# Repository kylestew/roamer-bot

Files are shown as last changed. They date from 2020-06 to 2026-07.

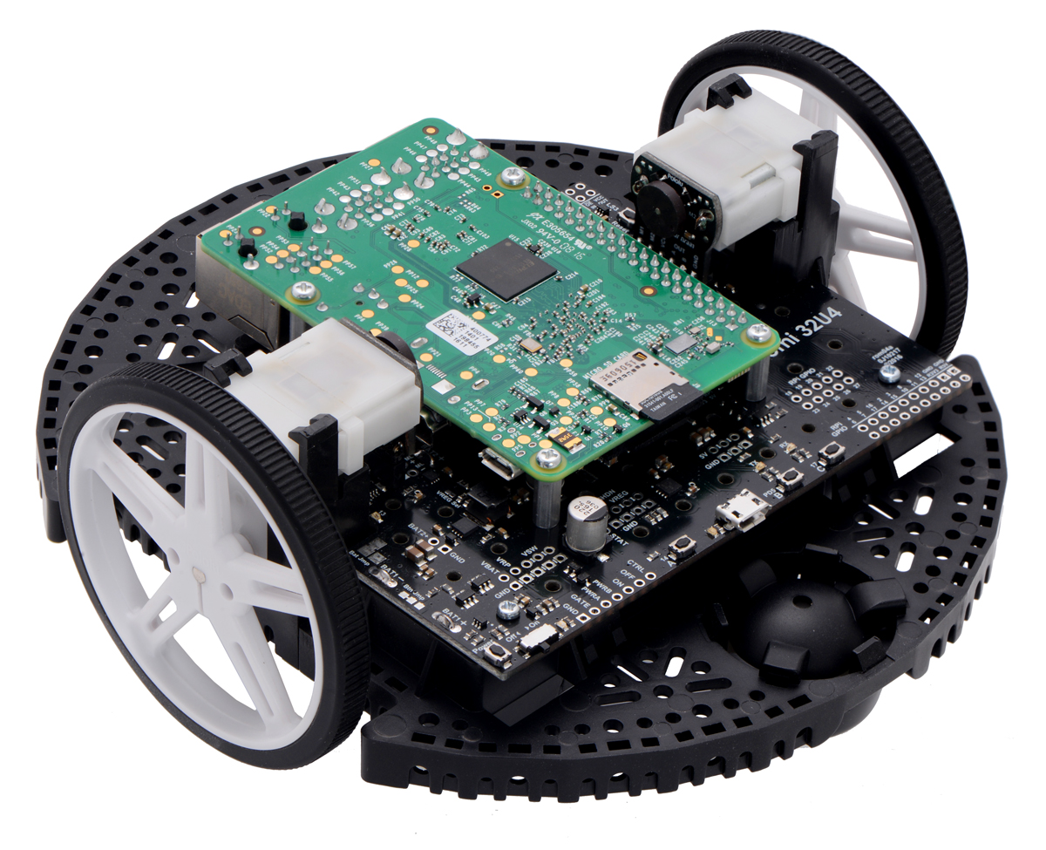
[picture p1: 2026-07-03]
docs/0J7520.1200.jpg

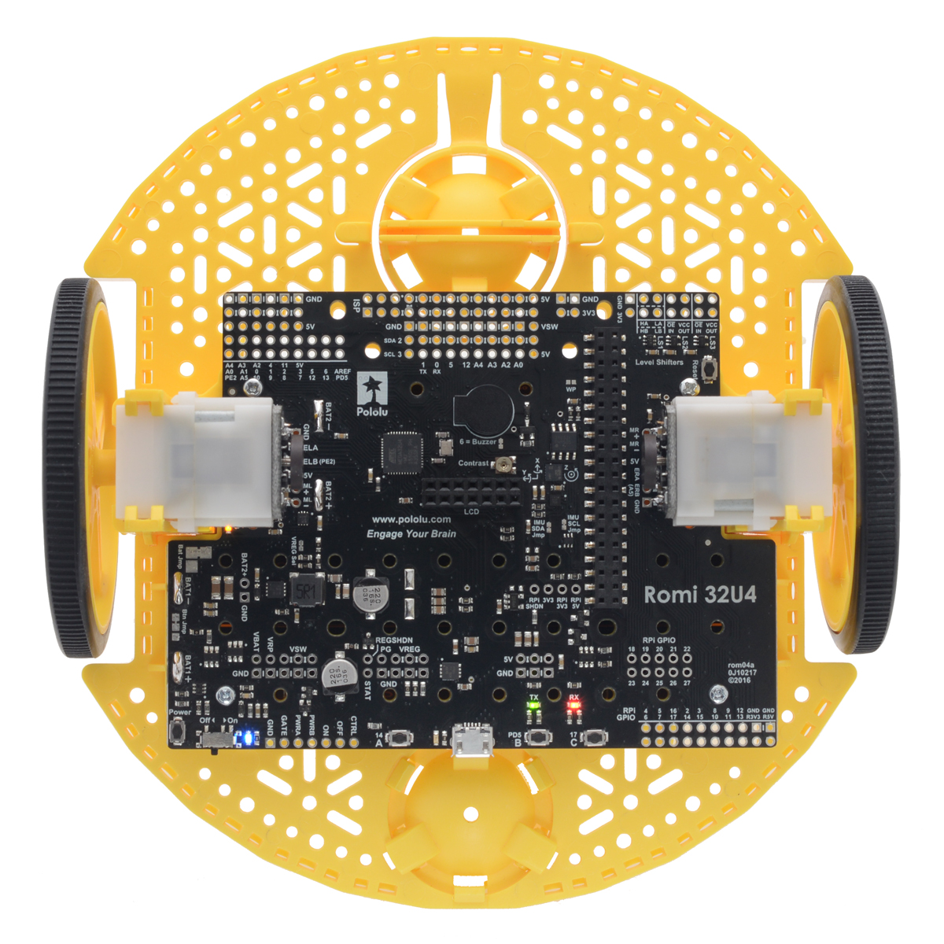
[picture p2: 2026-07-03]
docs/0J7519.1200.jpg

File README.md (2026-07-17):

# roamer-bot

A small robotics learning platform built on the Pololu Romi chassis.

The current direction is a custom-core Studio Mission Rover: Romi chassis, custom MCU + motor-control PCB, laptop tether first, telemetry from day one, and no ROS in the core system until the low-level robot is understood.

romi chassis

# Current Direction

The project is moving from the original Romi 32U4 + Raspberry Pi + ROS approach toward a custom-core learning build:

- Treat the old implementation as historical/reference material.
- Use the Romi chassis as the mechanical target.
- Build a custom MCU + motor-control PCB that replaces the purchasable Pololu Romi control board.
- Keep the first version tethered to a laptop.
- Capture telemetry from day one.
- Keep ROS out of the core system until the custom board, telemetry, and motor-control loop are understood.

# Current Structure

- `hardware/`: active Rev A PCB and mechanical-constraint work.
- `firmware/`: active custom MCU firmware work.
- `host/`: active laptop tether, telemetry capture, and test tooling work.
- `legacy/old-romi/`: previous Romi 32U4 + Raspberry Pi + ROS implementation, kept only as reference.
- `docs/`: datasheets, Romi reference assets, and legacy dependency references.

# Planning

- [Hardware design, release gate, and Rev B plan](hardware/README.md)
- [Studio Mission Rover roadmap](STUDIO_MISSION_ROVER_ROADMAP.md)
- [TO BUY list](TO_BUY.md)
- [Legacy Romi references](docs/legacy-romi-references.md)

# First Milestone

Teleop + encoder logging + safe stop:

- Command left and right motors from a laptop or simple host.
- Read left and right encoder counts.
- Stream basic telemetry.
- Stop motors on command timeout.
- Save a short bench or floor test log on the host.

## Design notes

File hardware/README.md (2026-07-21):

# Roamer Hardware

Status: **Rev A was ordered from JLCPCB on 2026-07-18 and is in production; fabrication and bring-up verification remain.**

This is the single source of truth for the custom Romi motor-controller hardware. If this document disagrees with the KiCad design, the schematic, PCB, and generated BOM are authoritative and this document must be corrected.

## Objective

Rev A replaces the Pololu Romi controller for the minimum useful rover loop:

- independently command two brushed DC motors;
- count both quadrature encoders in hardware;
- communicate with a laptop over native USB;
- report battery, motion, timeout, and reset state;
- stop both motors safely when commands cease; and
- mount directly to the Romi chassis and encoder boards.

Rev A is intentionally a focused learning board. It does not include an IMU, Raspberry Pi interface or power supply, wireless, charging, a 5 V accessory rail, or a polished multi-source power system.

Success means teleoperation, reliable encoder logging, useful telemetry, and an unconditional command-timeout stop during a short bench or floor run.

## Design Files

- [Top-level schematic](driver-board/driver-board.kicad_sch)
- [Power sheet](driver-board/power.kicad_sch)
- [Motor-control sheet](driver-board/motor_control.kicad_sch)
- [USB sheet](driver-board/usb.kicad_sch)
- [PCB](driver-board/driver-board.kicad_pcb)
- [KiCad project](driver-board/driver-board.kicad_pro)
- [Generated BOM snapshot](driver-board/driver-board.csv)
- [Rev A JLCPCB manufacturing release](releases/rev-a-jlcpcb-2026-07-18.md)
- [Custom footprints](driver-board/CustomParts.pretty/)

The checked-in CSV is a working snapshot, not purchase-ready assembly data. Regenerate and review the BOM and placement file from the final schematic and PCB immediately before ordering.

## Rev A Architecture

### Battery and power

Rev A is designed only for the Romi six-AA bay populated with rechargeable NiMH cells:

- nominal pack voltage: approximately 7.2 V;
- fresh-pack voltage: approximately 8.4 V;
- bench-supply ceiling: 8.5 V; and
- alkaline cells are prohibited because a fresh pack can approach 9.6 V, reducing DRV8838 transient margin and increasing motor stall current beyond the intended operating envelope.

The implemented load-current path is:

```text
BT1+ -> VBAT -> F1 -> Q1 -> VBAT_SAFE -> Q2 -> VBAT_SW
BT1- -> BT2+
BT2- -> GND
```

- F1 is a Littelfuse `MINISMDC260F/16-2` resettable PTC: 16 V, 2.6 A hold, 5 A trip.
- Q1 (`AO3401A`) provides reverse-battery protection.
- Q2 (`AO4407A`) is the high-side whole-board power MOSFET.
- SW2 (`SK-3296S-01-L2`) switches Q2's gate; it does not carry motor or regulator load current.
- `VBAT_SW` feeds both motor-driver VM inputs, both encoder boards, and the 3.3 V buck regulator.
- USB VBUS is used only around the USB interface. It does not power `+3V3`, the encoders, or the motors.

The LMR51430 buck, 5.6 uH L1, and output network generate approximately 3.3 V from `VBAT_SW`. There is no 5 V logic rail, separate `+3V3A` rail, or analog-rail inductor. VDDA is fed directly from `+3V3` with local 10 nF and 1 uF decoupling.

Battery telemetry uses a 100 kOhm / 33 kOhm divider into PB0/ADC1_IN8. Rev A deliberately omits a filter capacitor; firmware must use a long ADC sample time and modest averaging. This is approximate state telemetry, not precision fuel gauging.

### Motor power and protection

Rev A uses one TI DRV8838 per motor. The target motor is the Pololu #1520 120:1 high-power mini plastic gearmotor, specified around 3-6 V with approximately 1.25 A stall current at 4.5 V.

Normal firmware output is capped at 75% absolute PWM duty, following the Pololu Romi operating policy. Full-duty operation is diagnostic-only, with a current-limited supply and explicit test firmware.

Motor-rail capacitance is:

| Driver | VM high-frequency bypass | VM local storage | VCC bypass |
| --- | --- | --- | --- |
| U3, left | C11, 100 nF | C10, 10 uF | C12, 100 nF |
| U4, right | C14, 100 nF | C13, 10 uF | C15, 100 nF |

C16 is a shared 220 uF, 25 V bulk capacitor across `VBAT_SW` and GND. It buffers short current steps and returned energy but does not replace the battery as the sustained current source. Rev A has no TVS or characterized regenerative clamp; startup, stop, reversal, stall-release, and power-off peaks must be measured during bring-up.

Each DRV8838 `nSLEEP` input has a hardware pulldown. Firmware must also initialize `nSLEEP`, PWM/EN, and PH to disabled states before accepting commands. A host timeout, watchdog event, low-battery condition, or unsafe state commands PWM to zero and puts the drivers to sleep while the MCU remains powered.

DRV8838 provides no fault or current-sense output. Diagnose problems through commanded state, encoder response, battery voltage, reset cause, temperature, and measured supply waveforms.

### Motor and encoder connectors

The encoder boards are powered from `VBAT_SW` because their specified VCC range begins above 3.3 V. Their A/B outputs are open-drain and pulled up to `+3V3`, so the STM32 receives safe 3.3 V logic. Firmware must treat encoder counts as unreliable when the battery approaches the encoder's 3.5 V minimum plus margin.

Viewed from the top of the PCB:

| Connector | Top-to-bottom pin order |
| --- | --- |
| J4, left | `GND`, `ENC_L_A`, `ENC_L_B`, `VBAT_SW`, `ML+`, `ML-` |
| J3, right | `MR-`, `MR+`, `VBAT_SW`, `ENC_R_A`, `ENC_R_B`, `GND` |

The right connector is intentionally mirrored for cleaner symmetric routing and does not reproduce the Pololu silkscreen order. Confirm actual wheel-forward polarity and encoder count sign during bring-up; correct direction convention in firmware rather than casually changing the verified connector layout.

### MCU and firmware-facing pin contract

U1 is an `STM32F103CBT6` in LQFP-48 with a 16 MHz HSE crystal, native USB FS, SWD, two hardware encoder timers, two PWM channels, and battery ADC input.

| Function | MCU pin | Peripheral or mode |
| --- | --- | --- |
| Heartbeat LED | PC13 | GPIO, active-low |
| Left sleep | PB12 | GPIO, active-low |
| Left direction | PB13 | GPIO |
| Left PWM | PB14 | TIM1 CH2N |
| Right sleep | PB5 | GPIO, active-low |
| Right direction | PB6 | GPIO |
| Right PWM | PB7 | TIM4 CH2 |
| Left encoder A/B | PA6 / PA7 | TIM3 CH1 / CH2 |
| Right encoder A/B | PB3 / PA15 | TIM2 CH2 / CH1, partial remap 1 |
| Battery level | PB0 | ADC1 IN8 |
| USB D-/D+ | PA11 / PA12 | USB FS |
| SWDIO/SWCLK | PA13 / PA14 | SWD; SWO is not connected |

The MCU contains I2C2 on PB10/PB11, but those package pins are explicit no-connects on Rev A. There are no pullups, connector, or sensor footprint, so Rev A has no usable I2C bus. Remove the stale I2C2 assignment from the CubeMX design artifact before release. User buttons and additional controlled status LEDs are also deferred; Rev A has reset, a power LED, and one MCU heartbeat/status LED.

SWD is the primary programming and recovery path. The 1.27 mm 2x5 header exposes target power, GND, SWDIO, SWCLK, and NRST; the target supplies its own 3.3 V.

### USB policy

J2 is a USB-C USB 2.0 receptacle with 5.1 kOhm CC resistors and USBLC6-2 ESD protection. D+/D- run directly to the STM32 without external series resistors and are routed via-free on `F.Cu` over the solid ground plane.

Rev A is battery-powered and USB-data-only:

- USB alone leaves the board off.
- Battery/bench power with USB disconnected supports standalone operation.
- Battery/bench power plus USB supports programming, commands, and telemetry without backfeeding the board from VBUS.

R5 permanently enables the external D+ pullup whenever board 3.3 V is present; attachment is not gated by VBUS. Rev A therefore assumes connection to an already-powered host. If enumeration fails after connection to an unpowered or booting host, unplugging and reconnecting USB is the accepted recovery. Add VBUS sensing and pullup gating in Rev B if reliable or standards-compliant self-powered attachment is required.

## PCB and Manufacturing Policy

Rev A is a four-layer, approximately 1.6 mm FR-4 board:

| Layer | Primary use |
| --- | --- |
| `F.Cu` | Components, signals, short local power pours, and regulator switching loops |
| `In1.Cu` | Continuous GND plane; never split into motor and logic grounds |
| `In2.Cu` | `VBAT_SW` and `+3V3` power distribution |
| `B.Cu` | Lower-speed signals plus a stitched GND fill |

Rules to preserve:

- Keep USB, clocks, feedback, ADC, reset, and other sensitive signals over continuous ground.
- Do not route a bottom-layer signal across an `In2.Cu` power split without a same-layer or otherwise continuous return reference.
- Keep the U5 VIN, bootstrap, switch-node, inductor, output-capacitor, and feedback loops compact.
- Keep motor-current paths and returns short and broad, with multiple vias where current changes layers.
- Keep the DRV8838 exposed-pad solder areas free of drilled holes. The implemented nearby ordinary GND vias require no via-in-pad fill or cap process.
- Keep motor current away from encoder, USB, crystal, reset, SWD, and BATLEV routing.

The smallest intentional signal vias are 0.55 mm diameter with a 0.25 mm drill. These are within JLCPCB rigid-board capability and have a 0.15 mm radial annular ring. Continue to use 0.70/0.30 mm or larger vias for high-current, thermal, and principal ground paths when space permits.

Silkscreen is front-side only. The board includes assembly and connector labels, polarity and pin-1 marks, test-point labels, board/battery identification, and the capybara artwork. There is no back silkscreen.

Mechanical fit has been checked repeatedly against the Romi chassis, encoder boards, battery contacts, wheels, clips, ribs, caster area, mounting holes, switch access, and USB cable access. Preserve the verified board outline and chassis-critical footprints.

## Current Verification State

As of 2026-07-21:

- JLCPCB order `W2026071807372374` is in production and its PCB production file is confirmed;
- the order contains five PCBs, including two economically assembled PCBAs;
- fabrication completion and physical bring-up remain;
- schematic ERC: **0 violations**;
- PCB DRC: **0 violations**;
- PCB connectivity: **0 unconnected items**;
- SW2 SMD-anchor pad semantics and silkscreen clearances are fixed in both the library footprint and board instance; and
- top, bottom, and isometric views plus a 1:1 chassis comparison have been reviewed.

The KiCad project intentionally excludes several generic checks, including missing courtyards, track endpoints not centered on vias, tuning-profile geometry, footprint filters, and footprint type. A clean report means the active Rev A rule set passes; it does not replace the fabrication preview and manual checks below.

## Fabrication Release Gate

Complete every item before ordering:

- [ ] Remove the unusable I2C2 PB10/PB11 assignment from the CubeMX artifact and keep I2C, user buttons, and extra LEDs explicitly deferred to Rev B.
- [ ] Refill all zones, complete the final GND-stitching pass, and confirm no isolated copper islands.
- [ ] Rerun ERC and PCB DRC with schematic parity, warnings, exclusions, and zero unconnected items reviewed.
- [ ] Reinspect the complete power path, battery series link, Q1/Q2 orientation, both driver VM/output/ground loops, U5 layout, USB routing, NRST, BOOT0, oscillator, and MCU decoupling.
- [ ] Verify both `nSLEEP` pulldowns hold the drivers off during reset, boot, SWD attach, unpowered-MCU states, and firmware initialization.
- [ ] Verify BATLEV stability with motors and the buck switching; accept the unfiltered divider only if firmware sampling is adequate.
- [ ] Confirm the actual JLCPCB stackup and USB geometry, drill and slot sizes, annular rings, mask dams, copper-edge clearance, and silkscreen capability.
- [ ] Regenerate the BOM and CPL/position data from the final design.
- [ ] Fill or explicitly waive every missing JLCPCB field, especially C22, C23, R5, R12, R13, and R16-R19.
- [ ] Manually verify U1, U3/U4, U5, F1, Q1, Q2, SW2, J2, J3/J4, L1, C16, and C17-C21 against current value, package, polarity, voltage/current rating, lifecycle, and stock.
- [ ] Review Gerbers, drills, IPC netlist, BOM, and CPL independently, then inspect the JLCPCB fabrication and assembly previews for side, rotation, pin 1, polarity, DNP state, and footprint alignment.
- [ ] Archive the exact schematic, PCB, fabrication outputs, BOM, CPL, and firmware revision used for the build.

Useful release commands:

```sh
/Applications/KiCad/KiCad.app/Contents/MacOS/kicad-cli sch erc \
  --severity-all hardware/driver-board/driver-board.kicad_sch

/Applications/KiCad/KiCad.app/Contents/MacOS/kicad-cli pcb drc \
  --schematic-parity --severity-all \
  hardware/driver-board/driver-board.kicad_pcb
```

## Bring-Up Plan

1. Inspect polarity, orientation, shorts, solder joints, and the unpowered resistance of each rail.
2. Use a current-limited bench supply at a low voltage with motors disconnected; verify `VBAT`, `VBAT_SAFE`, `VBAT_SW`, and `+3V3` in order.
3. Verify SW2/Q2 behavior, Q1 reverse protection, no USB backfeed, and USB-only board-off behavior.
4. Attach SWD, confirm NRST/BOOT behavior, program the safe image, and prove both `nSLEEP` inputs and PWM outputs remain inactive through reset and debugger attach.
5. Confirm the 16 MHz HSE/48 MHz system clock, heartbeat LED, USB enumeration, battery ADC reading, and reset-cause telemetry.
6. Connect one motor and its encoder. Start at low duty, verify direction/count sign, sweep duty conservatively, and test timeout stop.
7. Repeat for the other motor, then operate both together while checking encoder integrity and the 3.3 V rail.
8. With a short oscilloscope ground spring, capture `VBAT_SW` at C16 and each driver during start, stop, reversal, simultaneous start, stall release, and power-off at nominal and fresh-pack voltage.
9. Check the PTC, MOSFETs, regulator, inductor, motor drivers, connectors, and C16 temperature during an extended test.
10. Run low-speed straight, turn, stop, and host-disconnect floor tests while saving telemetry.

Bring-up passes when both motors operate independently in both directions, encoder counts remain clean, PWM response is monotonic, command timeout and watchdog stop the motors, USB remains stable, and motor events do not reset the MCU or violate measured rail margins.

Record Rev A current, voltage transients, temperatures, resets, encoder errors, mechanical fit, and USB behavior. Those measurements—not guesses—select Rev B protection and power changes.

## Critical Parts

| Function | Part | Current JLCPCB/LCSC ID |
| --- | --- | --- |
| MCU | STM32F103CBT6 | C8304 |
| Motor drivers | DRV8838, U3/U4 | C86667 |
| Buck regulator | LMR51430XDDCR | C5185863 |
| Buck inductor | SWPA8065S5R6MT, 5.6 uH | C96977 |
| USB ESD | USBLC6-2SC6 | C7519 |
| USB-C connector | GT-USB-7010ASV | C2988369 |
| Input PTC | MINISMDC260F/16-2 | C16490 |
| Reverse-protection MOSFET | AO3401A | C15127 |
| Power MOSFET | AO4407A | C16072 |
| Power switch | SK-3296S-01-L2 | C500051 |
| Bulk capacitor | 220 uF, 25 V | C190724 |
| HSE crystal | 16 MHz, 3225 | C13738 |

Recheck every ID and stock state at order time; this table records the design, not a sourcing guarantee.

## Rev B Backlog

Rev B begins only after Rev A assembly and measured testing. Priorities are:

1. Correct every demonstrated Rev A electrical, mechanical, sourcing, or firmware-contract defect.
2. Retain USB and add a 3.3 V UART host interface; keep motor safety, encoder counting, timeout, and low-level control on the STM32.
3. Add a 6-axis IMU and an isolatable 3.3 V I2C/Qwiic-style sensor connector.
4. Consider an unpopulated Pi-compatible header, but default to a separately powered host sharing only communications and GND. Do not advertise HAT compatibility without meeting the complete specification.
5. Add VBUS sensing and gated USB attachment; optionally support USB/host-powered logic while guaranteeing the motor rail remains off and no source can backfeed another.
6. Add snubber, clamp/TVS, distributed bulk-capacitance, current-sense, or fault-reporting provisions only where Rev A measurements justify them.
7. Consider a diagnostic motor driver such as DRV8213 and a newer MCU such as STM32G0B1 only if Rev A exposes a concrete limitation.
8. Do not add a magnetometer beside motors or an unrestricted multi-amp Pi supply by default. Remote magnetic sensing and host power require explicit mechanical and power requirements.

Any host reset, disconnect, or brownout must still cause the STM32 watchdog to stop the motors safely.

## References and Asset Provenance

Local vendor references retained as primary sources:

- [STM32F103 datasheet](docs/stm32f103c8.pdf)
- [DRV8838 datasheet](docs/drv8838.pdf)
- [LMR51430 datasheet](docs/lmr51430.pdf)
- [AO4407A / C16072 reference](docs/C16072.pdf)
- [SK-3296S-01-L2 / C500051 reference](docs/C500051.pdf)
- [Reset switch / C720477 reference](docs/C720477.pdf)
- [Alternate switch / C1788495 reference](driver-board/datasheets/C1788495.pdf), not fitted on current Rev A

External design references:

- [Pololu Romi 32U4 control-board guide](https://www.pololu.com/docs/0J69/all)
- [Pololu Romi 32U4 resources](https://www.pololu.com/product/3544/resources)
- [Pololu #1520 motor](https://www.pololu.com/product/1520)
- [Pololu Romi encoder pair](https://www.pololu.com/product/3542)
- [ST USB hardware and PCB guidelines, AN4879](https://www.st.com/resource/en/application_note/an4879-introduction-to-usb-hardware-and-pcb-guidelines-using-stm32-mcus-stmicroelectronics.pdf)
- [Samsung CL21A106KAYNNNE data](https://product.samsungsem.com/mlcc/CL21A106KAYNNN.do)
- [Raspberry Pi hardware documentation](https://www.raspberrypi.com/documentation/computers/raspberry-pi.html)

3D-model provenance:

- `driver-board/3dmodels/GT-USB-7010ASV.step` comes from the GPL-2.0-licensed [MiSTerLaggy_MiSTer hardware repository](https://github.com/MiSTer-devel/MiSTerLaggy_MiSTer/blob/main/hardware/GT-USB-7010ASV.step).
- `driver-board/3dmodels/SK-3296S-01-L2.wrl` was converted without changing millimetre-scale alignment from the [EasyEDA model](https://modules.easyeda.com/3dmodel/a3deeb560a8c4467ab29e6daf75b62b9) for [LCSC C500051](https://www.lcsc.com/product-detail/Electrical-Switches_XKB-Connectivity-SK-3296S-01-L2_C500051.html).

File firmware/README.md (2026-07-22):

# Firmware

Active firmware work for the STM32 MCU on the Rev A motor-control board.

The firmware is bare-metal C11 for the `STM32F103CBT6`. It uses CMSIS register
definitions but no STM32 HAL, LL framework, RTOS, heap, or generated runtime
code. [`roamer_rev_a.ioc`](roamer_rev_a.ioc) records the planned pin and clock
assignment; it is a design artifact rather than the firmware generator.

## Build

Requirements:

- Arm GNU Toolchain (`arm-none-eabi-gcc`, `objcopy`, and `size`)
- CMake 3.22 or newer
- Ninja

From the repository root:

```sh
cmake -S firmware -B firmware/build-debug -G Ninja -DCMAKE_BUILD_TYPE=Debug
cmake --build firmware/build-debug

cmake -S firmware -B firmware/build-release -G Ninja -DCMAKE_BUILD_TYPE=Release
cmake --build firmware/build-release
```

Each build produces `roamer_rev_a.elf`, `.hex`, `.bin`, and `.map` files and
prints Flash/RAM use.

## Program and debug

SWD is the primary programming and recovery interface. The board has a
1.27 mm MIPI10/Arm Cortex debug header; an STLINK-V3SET includes the matching
cable. The target must supply its own 3.3 V power. Keep the motors disconnected
during initial bring-up.

With `STM32_Programmer_CLI` on `PATH` and an ST-LINK attached:

```sh
STM32_Programmer_CLI -c port=SWD -w firmware/build-release/roamer_rev_a.hex -v -rst
```

The initial image keeps both DRV8838 drivers asleep and both PWM inputs low.
PC13 blinks with a one-second cycle after the 16 MHz HSE starts and the system
switches to 48 MHz. A rapid blink indicates that firmware remained on the
8 MHz internal oscillator because HSE startup failed. USB is enabled only when
the 48 MHz clock is available.

## USB heartbeat bring-up

Rev A is self-powered and uses USB only for data. Power the board from its
battery or a current-limited bench supply, connect it to an already-powered
host, and then look for the CDC ACM serial device. USB alone does not power the
board.

On macOS, find and open the device with:

```sh
ls /dev/cu.usbmodem*
screen /dev/cu.usbmodem* 115200
```

The baud-rate setting is accepted for CDC compatibility but does not control a
physical UART. While the serial port is open, the firmware sends one line per
second:

```text
roamer heartbeat
```

Close `screen` with `Ctrl-A`, then `\`. The PC13 LED continues blinking while
USB is connected. Motor commands and received serial data are not supported by
this bring-up image; received bytes are discarded and both drivers remain
asleep.

The USB identity is development-only: VID `0xCAFE`, PID `0x4001`, manufacturer
`Roamer`, and product `Roamer Rev A`. The serial string comes from the MCU's
96-bit unique ID. Replace the prototype VID/PID with assigned values before any
product distribution.

Rev A has a permanently enabled D+ pullup and no VBUS sensing. Firmware pulses
D+ low during startup to encourage clean re-enumeration after reset, but if the
host does not rediscover the device, unplug and reconnect the USB cable as
documented in the hardware policy.

## Verified Rev A pin contract

| Function | MCU pin | Peripheral/mode |
| --- | --- | --- |
| Heartbeat LED | PC13 | GPIO, active-low |
| Left sleep | PB12 | GPIO, active-low |
| Left direction | PB13 | GPIO |
| Left PWM | PB14 | TIM1 CH2N |
| Right sleep | PB5 | GPIO, active-low |
| Right direction | PB6 | GPIO |
| Right PWM | PB7 | TIM4 CH2 |
| Left encoder A/B | PA6 / PA7 | TIM3 CH1 / CH2 |
| Right encoder A/B | PB3 / PA15 | TIM2 CH2 / CH1, partial remap 1 |
| Battery level | PB0 | ADC1 IN8 |
| USB D-/D+ | PA11 / PA12 | USB FS |
| SWDIO/SWCLK | PA13 / PA14 | Debug; SWO is not connected |

The CubeMX design artifact also assigns I2C2 SCL/SDA to PB10/PB11, but those two MCU pads are explicit no-connects in the Rev A schematic and PCB. There are no I2C pullups or external connection, so I2C2 is not physically usable on the current board. Route it before fabrication or remove the assignment and explicitly descope the Rev A expansion bus.

Initial firmware should support independent left/right motor commands, encoder counting, basic telemetry, battery reporting, and command-timeout safe stop.

Hardware-facing firmware requirements are tracked in the [Rev A hardware specification](../hardware/README.md#mcu-and-firmware-facing-pin-contract).

Accepted behavior and safety policies are tracked in [Rev A firmware design](DESIGN.md), including the six-cell NiMH motor-power baseline and 75% normal-duty ceiling.

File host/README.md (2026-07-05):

# Host

Active laptop-side tooling for Rev A bring-up.

Initial host tools should send motor commands over USB or serial, capture telemetry, save short run logs, and make bench/floor tests repeatable.

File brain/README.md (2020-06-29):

# Brain - ROS workspace for Roamer Bot

### Notes:

brainstem package requires sudo-less i2c permissions 
https://lexruee.ch/setting-i2c-permissions-for-non-root-users.html

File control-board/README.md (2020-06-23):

# 32U4 Control Board

Provides the low-level operations for the Roamer Robot:

+ Motor control (w/PID) takes ROS Twist command data
+ Encoders publish robot ODOM
+ IMU publishes robot POSE
+ Auto shutdown if new Twist command not received in a defined period
+ Buttons
+ LEDs
+ Battery voltage

### I2C Interface

Bi-directional via a struct
???

## CLI Commands

Build firmware

    $ pio run -e robot

Upload firmware via bootloader

    $ pio run -e robot -t upload

Run native desktop test

    $ pio test -e native 

Run embedded test

    $ pio test -e robot

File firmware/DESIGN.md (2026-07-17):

# Rev A Firmware Design

Status: active decisions

This document records firmware behavior that is required by the Rev A hardware. Hardware-level requirements remain in the [Rev A hardware specification](../hardware/README.md).

## Motor and battery baseline

Rev A intentionally follows the proven Pololu Romi motor-power approach:

| Item | Rev A decision |
|---|---|
| Motor | [Pololu #1520](https://www.pololu.com/product/1520), 120:1 mini plastic gearmotor HP |
| Motor specification | 4.5 V intended, 3–6 V comfortable range, 1.25 A stall at 4.5 V |
| Battery | Six rechargeable AA NiMH cells only |
| Pack voltage | About 7.2 V nominal and approximately 8.4 V when freshly charged |
| Motor driver | One DRV8838 per motor |
| Driver supply | Raw reverse-protected and switched battery rail, `VBAT_SW` |
| Normal PWM ceiling | 75% absolute duty cycle |

Alkaline cells are outside the Rev A operating specification. Six alkaline cells have a substantially higher pack voltage than six NiMH cells and must not be treated as an interchangeable option.

Pololu's Romi 32U4 board uses the same motors, six-cell battery arrangement, raw switched battery motor supply, and DRV8838 drivers. Its normal motor API limits output to 300 of 400 PWM counts, or 75% duty. Pololu describes the full 400-count range as turbo mode and warns that it can reduce motor lifetime.

## Motor output policy

- Clamp every open-loop, closed-loop, and host-requested motor command to an absolute duty cycle of `0.75` in normal operation.
- Apply the clamp at the final driver-output boundary as well as at command parsing. A malformed host command or controller wind-up must not bypass it.
- Do not expose turbo/full-duty operation in the normal Rev A host protocol.
- Full-duty testing, if ever needed, is a deliberate diagnostic operation performed locally with a current-limited bench supply and explicit test firmware.
- Battery-voltage feed-forward may reduce duty or improve repeatability below the ceiling. It must not silently raise the 75% ceiling.
- Record both requested and applied duty in telemetry so saturation is visible.

The 75% limit gives a rough effective motor voltage of 5.4 V from a 7.2 V pack and 6.3 V from an 8.4 V fresh pack. PWM is not identical to powering a motor from a lower DC voltage, so the limit does not guarantee current, thermal, or transient margin. Rev A accepts motor-rail transient characterization as deferred Rev B work.

## Driver state and safe stop

The DRV8838 PH/EN interface has an important semantic detail: `EN/PWM = 0` while awake commands brake, not coast. Pulling `nSLEEP` low disables the bridge and allows the motor to coast.

Required behavior:

1. Keep both drivers asleep during reset and early boot.
2. Initialize PWM to zero and direction to a known value before raising either `nSLEEP` signal.
3. Accept motor commands only after initialization and command-channel readiness.
4. On command timeout, malformed command, firmware fault, or explicit disable: set PWM to zero, then pull both `nSLEEP` signals low.
5. Use 1000 ms as the initial command-timeout value; tune it later from command rate and measured stopping distance.
6. Require a new valid command sequence before re-enabling after a timeout or fault.
7. Never create torque during reset, boot, USB enumeration, host disconnect, or brownout recovery.

## Battery and drivetrain telemetry

`BATLEV` is intentionally a coarse battery estimate, not a precision measurement. Use an ADC sample time of at least 41.5 cycles, preferably 55.5 cycles, to accommodate the 100 kΩ/33 kΩ divider's source impedance. Apply modest averaging and the nominal divider ratio. No dedicated filter capacitor or production calibration is required, and firmware must not depend on a narrow BATLEV threshold for safety-critical behavior.

Minimum telemetry:

- measured battery voltage;
- requested and applied duty for each motor;
- active 75% duty ceiling and whether either command is saturated;
- direction and sleep state for each motor;
- encoder count and estimated wheel speed for each side;
- command age and timeout state;
- reset and brownout cause when available; and
- an inferred stall warning when substantial applied duty produces no encoder motion.

The DRV8838 provides neither a fault output nor current sensing, so firmware cannot directly identify over-current or thermal shutdown. Telemetry must not claim that an inferred stall is a measured driver fault.

## Encoder handling

- Verify the physical left/right direction convention during bring-up.
- Positive commands should produce forward wheel motion and positive encoder accumulation on both sides after the documented sign corrections.
- Handle hardware counter wrap with modular deltas and accumulate position in a wider software integer.
- Treat encoder data as unreliable if the switched battery rail falls close to the encoder board's minimum supply voltage.

## Board indicators

- D2, the PC13 status LED, is active-low.
- Drive PC13 low to turn D2 on and high to turn it off.
- Keep PC13 configured so it sinks LED current; do not reconfigure the circuit or firmware around sourcing current from PC13.

## Required validation

Before normal unrestricted use:

1. Bring up each motor independently from a current-limited bench supply at low duty.
2. Verify forward/reverse direction and encoder sign for both sides.
3. Sweep duty through the permitted range and confirm monotonic unloaded speed.
4. Repeat with fresh and depleted six-cell NiMH packs.
5. Run both motors together and confirm clean encoder readings and stable logic power.
6. Briefly test single- and dual-motor stalls within controlled limits while observing supply current and driver temperature.
7. Measure driver and motor temperature during representative driving.
8. Confirm the timeout and every reset/disconnect path puts both drivers to sleep.

Motor-rail transient characterization during braking, reversal, stall release, and power switch-off is planned for Rev B rather than being a Rev A acceptance criterion.

## References

- [Pololu #1520 motor](https://www.pololu.com/product/1520)
- [Pololu Romi motor drivers and encoders](https://www.pololu.com/docs/0J69/3.3)
- [Pololu Romi power architecture](https://www.pololu.com/docs/0J69/3.5)
- [Pololu Romi motor library](https://pololu.github.io/romi-32u4-arduino-library/class_romi32_u4_motors.html)
- [Pololu support explanation of the 75% limit](https://forum.pololu.com/t/isnt-the-9v-of-the-romi-batteries-too-high-for-the-4-5v-gearmotors/17486)
- [TI DRV8838 datasheet](https://www.ti.com/lit/ds/symlink/drv8838.pdf)

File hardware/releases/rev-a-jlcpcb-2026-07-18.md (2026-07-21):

# Rev A JLCPCB Manufacturing Release

Status: **In production as of 2026-07-21.**

This record identifies the first Rev A fabrication and assembly run and the exact local upload artifacts retained with the project.

## Order Record

The JLCPCB order page displayed the following information:

| Item | Recorded value |
| --- | --- |
| Order time | 2026-07-18 00:37:30, as displayed by JLCPCB |
| JLCPCB order | `W2026071807372374` |
| Overall status | In Production |
| PCB product | PCB Prototype |
| PCB order | `Y15-03620135F` |
| PCB quantity | 5 pieces |
| PCB build estimate | 3 days |
| PCB price | $30.98 |
| PCB production file | `Archive_Y15`; confirmed |
| Assembly product | Economic PCBA |
| PCBA order | Displayed beginning `SMT026071763327-362`; suffix not visible in the retained screenshot |
| PCBA quantity | 2 pieces |
| PCBA build estimate | 4 days |
| PCBA price | $84.98 |
| Assembly BOM | `driver-board-jlc-bom.csv` |
| Assembly CPL | `driver-board-jlc-cpl.csv` |
| Merchandise total | $115.96 |
| Shipping | $24.55 |
| Customs duties and taxes | $28.09 |
| Order total | $168.60 |

The order page does not show stackup, copper weight, surface finish, colour, or the other detailed fabrication selections. If those settings are later exported from JLCPCB, add them here without changing the archived upload artifacts.

## Archived Upload Artifacts

| File | SHA-256 |
| --- | --- |
| `driver-board/mfr/Archive.zip` | `2fa4bc9299dedf3daeadd7bcf76799896939166ab728aa14c1a1434a415308a5` |
| `driver-board/mfr/driver-board-jlc-bom.csv` | `09befc26d306caf2595d57af9a16463424a30b2fd342b907b6d6cff0e5063712` |
| `driver-board/mfr/driver-board-jlc-cpl.csv` | `672cb036feffceff9ac96b1f98a63404802aedea3e041ae011d15d0772670f0f` |

`Archive.zip` contains the submitted four-layer Gerbers and plated/non-plated drill files. The BOM and CPL are retained separately because JLCPCB accepts them as separate assembly uploads.

The Git tag `rev-a-jlcpcb-2026-07-18` identifies the repository checkpoint for this manufacturing run.

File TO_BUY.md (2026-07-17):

# TO BUY

Last reviewed: 2026-07-17

This is the purchasing list for the Rev A milestone: tethered teleoperation, encoder logging, and safe stop. Existing workshop and legacy-Romi inventory has not yet been checked, so items marked "if not already owned" should be verified before ordering.

## Buy Now

- [ ] **8 x AA NiMH cells from one matching batch.** Recommended: standard white Panasonic eneloop, 1.2 V, 1900 mAh minimum. The rover uses six cells; label and keep six as one set and retain two as spares. Buy twelve instead if a complete second six-cell set is useful.
  - Rev A is NiMH-only: about 7.2 V nominal and up to about 8.4 V just charged.
  - Do not use alkaline, 1.5 V lithium, or regulated/rechargeable 1.5 V AA cells.
  - Product reference: <https://www.panasonic.com/global/energy/products/eneloop/en/lineup/eneloop.html>
- [ ] **One individual-channel AA NiMH charger.** Recommended: Panasonic eneloop `BQ-CC63` eight-slot charger, in the UK-plug version. It charges and terminates each of 1-8 cells independently, so all six rover cells can be charged in one pass.
  - Charge the loose cells in the charger, not in the rover.
  - Product reference: <https://www.panasonic.com/global/energy/products/eneloop/en/lineup/charger-bq-cc63.html>
- [x] **One Pololu Romi Chassis Kit — purchased.** Any colour is electrically equivalent; the current project reference is white, Pololu `#3509`.
  - Includes chassis, two 120:1 HP motors, motor clips, two wheels, one ball caster, and the complete battery-contact set.
  - Product reference: <https://www.pololu.com/product/3509>
- [x] **One Pololu Romi Encoder Pair Kit — purchased.** Pololu `#3542`.
  - Includes two encoder boards, two magnetic discs, and the low-profile male/female headers needed by the custom PCB.
  - Product reference: <https://www.pololu.com/product/3542>
- [ ] **#2-56 mounting hardware:** at least four 3/16-inch screws and four nuts; buying a packet of ten gives useful spares. The chassis kit does not include this hardware.

The chassis and encoder kit should be in hand before PCB release so battery-tab polarity, connector fit, header height, and board clearance can be checked physically.

## Needed Before First Power-On

- [ ] **One SWD programmer/debugger with a Cortex-M MIPI-10 cable**, if not already owned. The PCB uses a keyed 10-pin, 1.27 mm ARM SWD connector.
  - Turnkey recommendation: genuine `STLINK-V3SET`, which includes the STDC14-to-MIPI10 cable.
  - Do not buy an `STLINK-V3MINIE` alone for this board; it includes only an STDC14-to-STDC14 cable, so it also needs a separate STDC14-to-MIPI10 adapter cable.
  - Product reference: <https://www.st.com/en/development-tools/stlink-v3set.html>
- [ ] **One long, flexible USB 2.0 data cable** for tethered telemetry: USB-C at the rover end and the connector required by the development laptop at the host end.
  - Recommended starting length: 3 m. This should give useful floor-test range without excessive cable weight or drag.
  - It must carry data, not be a charge-only cable; prefer a USB-IF-certified cable from a reputable manufacturer.
  - USB 2.0 allows up to 5 m for a passive cable. For a longer tether, use a compliant active USB 2.0 extension/repeater rather than chaining passive extension leads.
- [ ] **Light cable strain relief:** a reusable hook-and-loop tie or clip that transfers cable pull to the chassis instead of the PCB's USB-C socket. Leave a small service loop at the connector.
- [ ] **Current-limited bench supply**, if not already owned or borrowable: adjustable through 0-8.5 V, CV/CC operation, output-enable button, and preferably at least 5 A available. Start bring-up with a much lower current limit and one motor at low duty.
- [ ] **Digital multimeter**, if not already owned, with DC voltage, resistance/continuity, diode test, and at least 5 A fused DC-current capability.
- [ ] **Two pairs of safe bench leads:** 4 mm banana leads plus insulated mini-grabbers or hook clips. Final probe/lead choice depends on the board's still-open bench-power and test-loop decision.
- [ ] **Assembly tools**, if missing:
  - temperature-controlled soldering iron and suitable small tip
  - electronics solder and flux
  - solder wick
  - fine tweezers and small pliers
  - flush cutters
  - small Phillips screwdriver
  - isopropyl alcohol and a small cleaning brush
  - eye protection and fume extraction

## Order When Rev A Is Released

Do not place this order until routing, DRC, mechanical checks, BOM regeneration, and the assembler preview are complete.

- [ ] **Five four-layer Rev A PCBs**, with at least three SMT-assembled. Keep more than one assembled board so a damaged bring-up board does not stop firmware work.
- [ ] **SMT assembly from the released BOM and placement files.** Check every extended part, rotation, side, and out-of-stock substitution in the upload preview.
- [ ] **Any hand-soldered test loops or test header** chosen during the final test-access decision.
- [ ] **Spare low-profile 1x6 header pair only if needed.** The new Pololu encoder kit already supplies the normal pair; first verify that its physical parts fit `J3` and `J4` as intended.

The Romi battery terminals and encoder headers will be hand-soldered after the assembled PCBs arrive. They are supplied by the chassis and encoder kits, respectively.

## Borrow or Buy Before Full Motor Characterisation

- [ ] **Two-channel oscilloscope**, ideally 50 MHz or better, with switchable 10x probes and short ground springs. This is useful for checking `VBAT_SW`, 3.3 V droop, PWM, reset, and encoder integrity during motor starts, stops, and reversals. Borrowing one is entirely reasonable for Rev A.

## Deliberately Not Buying for Rev A

- Pololu Romi control board or motor-driver board; the custom PCB replaces it.
- Raspberry Pi or other onboard computer.
- IMU, compass, lidar, camera, range sensors, or sensor expansion hardware.
- A second caster or expansion deck.
- Onboard NiMH charging circuitry.
- Alkaline or 1.5 V lithium AA cells.

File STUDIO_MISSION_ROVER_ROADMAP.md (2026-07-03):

# Studio Mission Rover Roadmap

Status: draft

## Thesis

The next `roamer-bot` revision should be a small, serviceable mobile robot that runs bounded indoor missions, logs telemetry, exposes its internal state, handles simple faults, and produces a post-run artifact such as a path image, run report, field note, or replay.

This is not another generic robot car. It is a learning platform for:

- Embedded motor control.
- Odometry.
- Coordinate frames.
- Sensor integration.
- State estimation.
- Autonomy modes.
- Fault handling.
- Telemetry.
- Replay.
- Human-facing debugging.
- Artifact generation.

## Architecture Stance

Build the core system yourself first. Do not start with ROS.

For v0 and probably v1, the rover should use a custom, understandable stack:

- MCU firmware for motor control, encoder reading, watchdogs, and hardware fault flags.
- Custom rover electronics, including the motor-driver board or motor-driver section.
- A small serial protocol between MCU and host.
- A custom mission runner on laptop first.
- Explicit odometry code.
- Explicit coordinate-frame structs and transforms.
- A custom telemetry log format.
- A simple ground console.
- A custom replay/artifact generator.

Add ROS later only when the custom core is already working and the reason is concrete:

- Bridge logs into standard visualization tools.
- Compare custom frame handling with `tf2`.
- Record or replay with bags.
- Experiment with Nav2.
- Integrate a sensor whose ROS driver saves major effort.

Rule:

> Build the robot's nervous system yourself first. Add ROS only when you can explain exactly what it is replacing.

## First Milestone

Teleop + encoder logging + safe stop.

That means:

- Custom board can command left/right motors.
- Encoders are read reliably.
- Host can send commands over USB/serial.
- Board streams basic telemetry.
- Command timeout stops the motors.
- A short run log is saved on the host.

## What This Teaches

Algorithm experience:

- Differential-drive kinematics.
- Encoder odometry.
- PID or velocity control.
- Sensor filtering.
- Coordinate frames.
- Obstacle detection later.
- Local navigation behaviors later.
- State machines.
- Fault detection and recovery.

Systems integration experience:

- MCU firmware and host software cooperating.
- Motors, encoders, batteries, sensors, and compute working as one system.
- Timing and message rates being managed.
- Telemetry being structured.
- Hardware failures becoming diagnosable.
- Run data becoming a tool for improvement.

## What To Defer

- ROS.
- SLAM.
- Nav2.
- Cameras.
- Onboard computer.
- IMU.
- Custom mechanical chassis.
- Full Romi 32U4 feature clone.

## Near-Term Sequence

1. Order Romi chassis/encoder parts.
2. Inspect physical chassis and encoder geometry.
3. Extract mounting holes, encoder mating geometry, battery contact geometry, and clearances.
4. Decide whether to build Board 0 or jump to Board 1.
5. Choose MCU and motor-driver IC.
6. Design Board 1 schematic.
7. Design Board 1 PCB around Romi mounting/encoder constraints.
8. Bring up motor drive, encoders, telemetry, and safe stop before adding higher-level behavior.

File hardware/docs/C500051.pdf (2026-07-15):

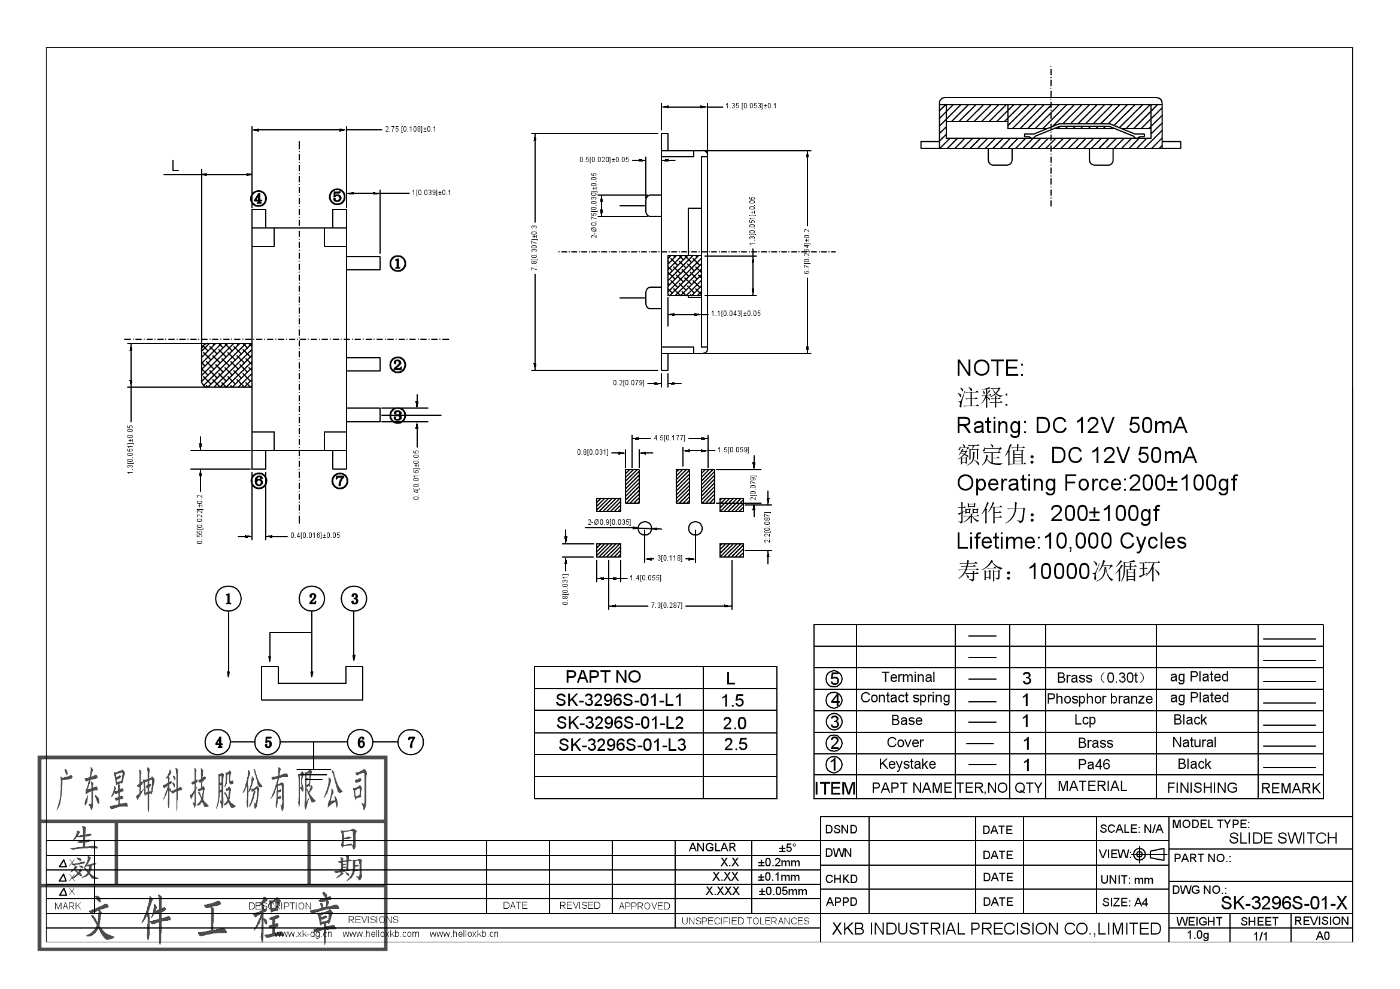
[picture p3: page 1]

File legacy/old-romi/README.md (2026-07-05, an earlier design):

# Old Romi Implementation

This directory contains the previous Romi 32U4 + Raspberry Pi + ROS implementation.

It is kept as historical/reference material only. The active project is the custom-core Studio Mission Rover work in `hardware/`, `firmware/`, and `host/`.

Useful reference areas:

- `control-board/`: 32U4 firmware, motor PID, encoder RPM, kinematics, odometry, command timeout, and battery reporting.
- `brain/`: old ROS workspace, I2C host driver, `cmd_vel` bridge, odometry publishing, and battery publishing.

The old Git submodules are intentionally removed. Their URLs and pinned commits are documented in [Legacy Romi references](../../docs/legacy-romi-references.md).

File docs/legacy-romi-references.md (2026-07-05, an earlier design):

# Legacy Romi References

The old Romi 32U4 + Raspberry Pi + ROS implementation has been moved to `legacy/old-romi/`.

These projects used to be Git submodules. They are no longer active dependencies of this repo, but the old URLs and pinned commits are preserved here for historical reference.

| Project | URL | Old pinned commit |
| --- | --- | --- |
| Pololu Romi 32U4 Arduino Library | https://github.com/pololu/romi-32u4-arduino-library.git | `86ed35f2ad56947020091cefc4921d37ab0378cd` |
| Linorobot PID | https://github.com/linorobot/lino_pid.git | `e248c5e8e5f2e4961d8f2d188421c09610b43e85` |
| Linorobot messages | https://github.com/linorobot/lino_msgs.git | `e6a37f7deb8351d7022eaf37b9af9277f3a965cf` |

The active custom-core project should not depend on these packages. Use the old code only for reference patterns such as command timeout, PID structure, odometry math, kinematics separation, I2C message shape, and battery handling.

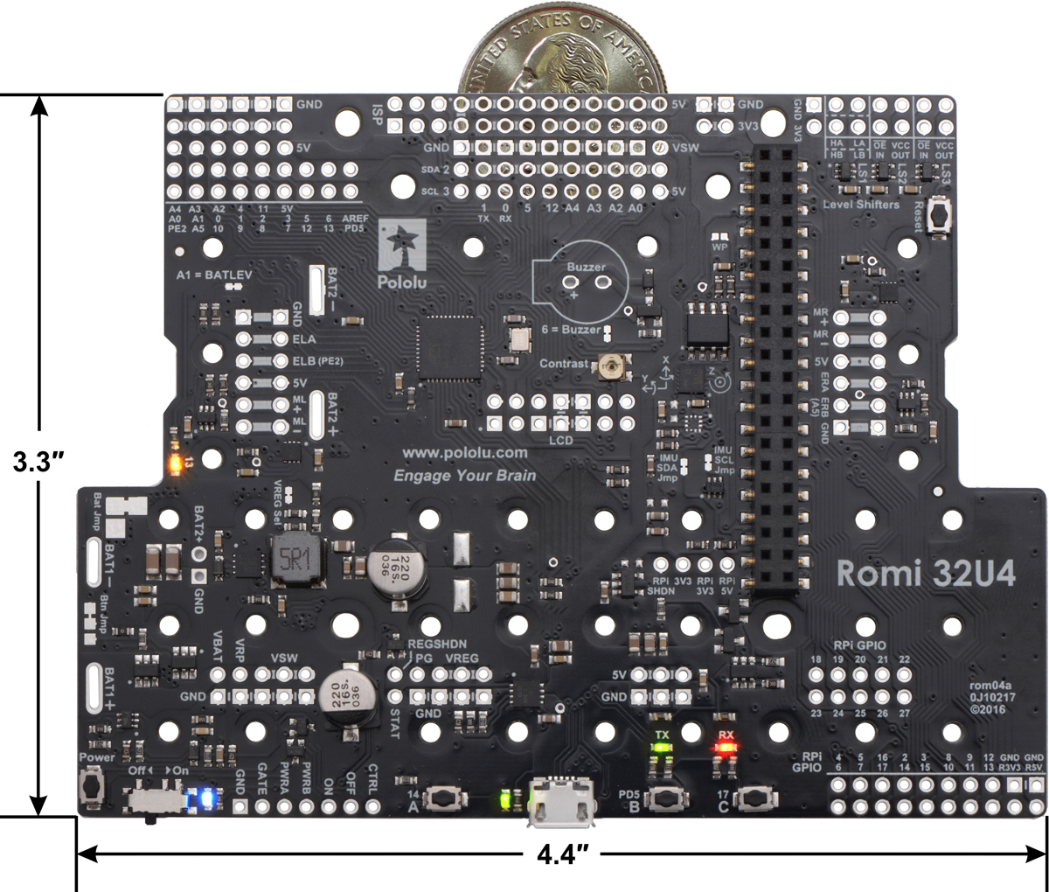
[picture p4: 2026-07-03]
docs/0J7517.1200.jpg

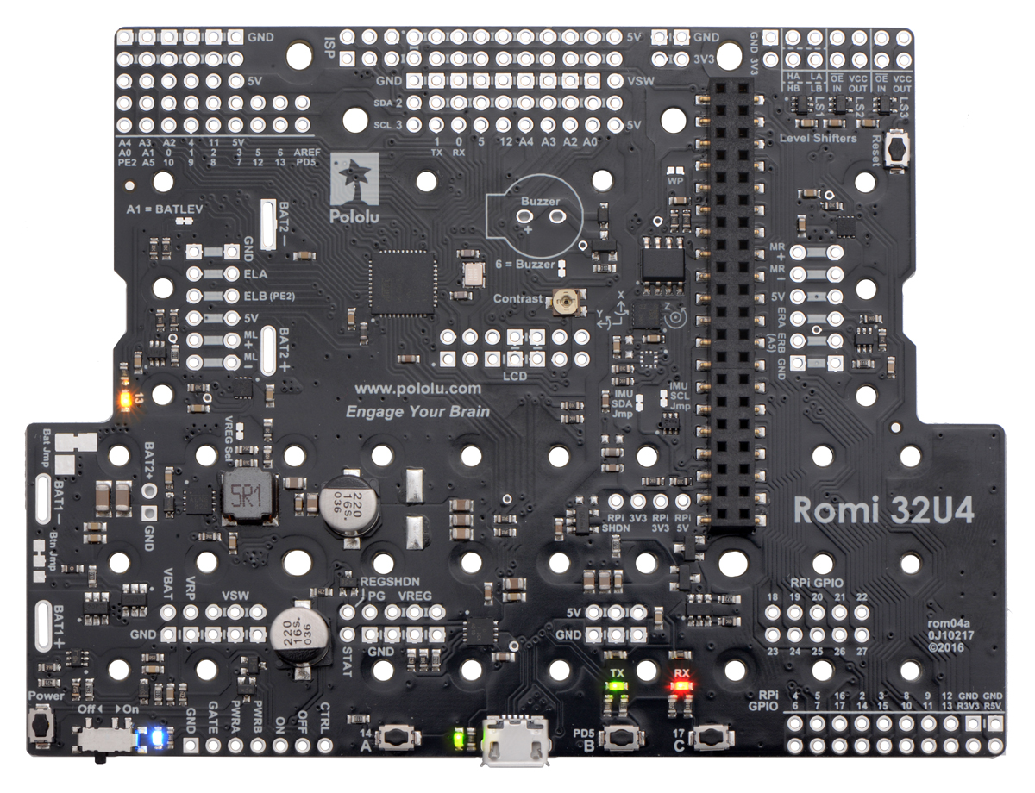
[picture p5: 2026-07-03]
docs/0J7509.1200.jpg

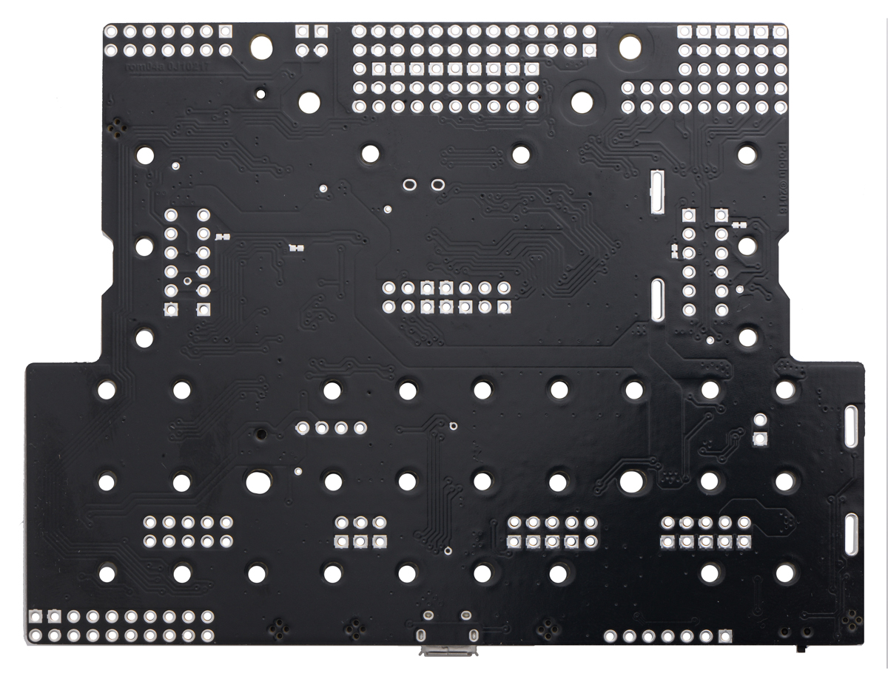
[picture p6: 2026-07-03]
docs/0J7508.1200.jpg

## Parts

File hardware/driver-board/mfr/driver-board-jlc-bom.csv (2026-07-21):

Comment | Designator | Footprint | JLCPCB Part #（optional）
10p | C1,C2 | Capacitor_SMD:C_0402_1005Metric | C32949
100n | C3,C4,C5,C6,C7,C9,C11,C12,C14,C15,C18,C19 | Capacitor_SMD:C_0402_1005Metric | C307331
10u | C8,C10,C13,C17 | Capacitor_SMD:C_0805_2012Metric | C15850
220u | C16 | Capacitor_SMD:CP_Elec_6.3x7.7 | C190724
22u | C20,C21 | Capacitor_SMD:C_1206_3216Metric | C12891
10n | C22 | Capacitor_SMD:C_0402_1005Metric | C15195
1u | C23 | Capacitor_SMD:C_0603_1608Metric | C15849
PWR_ON_LED | D1 | LED_SMD:LED_0603_1608Metric | C2286
STATUS | D2 | LED_SMD:LED_0805_2012Metric | C2297
PTC_2.6A_16V | F1 | Fuse:Fuse_1812_4532Metric | C16490
Conn_ARM_JTAG_SWD_10 | J1 | Connector_PinHeader_1.27mm:PinHeader_2x05_P1.27mm_Vertical_SMD | C2932107
USB_C_Receptacle_USB2.0_16P | J2 | Connector_USB:USB_C_Receptacle_G-Switch_GT-USB-7010ASV | C2988369
5.6u | L1 | Inductor_SMD:L_APV_ANR8065 | C96977
AO3401A | Q1 | Package_TO_SOT_SMD:SOT-23 | C15127
AO4407A | Q2 | CustomParts:AO4407A_SO-8_GSD | C16072
10k | R1,R10,R11,R14,R15 | Resistor_SMD:R_0402_1005Metric | C25744
1k5 | R5 | Resistor_SMD:R_0402_1005Metric | C25867
5k1 | R6,R7 | Resistor_SMD:R_0402_1005Metric | C25905
100k | R12,R13,R16,R18 | Resistor_SMD:R_0402_1005Metric | C25741
33k | R17 | Resistor_SMD:R_0402_1005Metric | C25779
22.1k | R19 | Resistor_SMD:R_0402_1005Metric | C43473
1k | R20,R21,R23 | Resistor_SMD:R_0603_1608Metric | C21190
100k | R22 | Resistor_SMD:R_0603_1608Metric | C25803
SW_Push | SW1 | Button_Switch_SMD:SW_SPST_TS-1088-xR020 | C720477
SK-3296S-01-L2 | SW2 | CustomParts:SW_SPDT_RightAngle_XKB_SK-3296S-01-L2 | C500051
STM32F103CBT6 | U1 | Package_QFP:LQFP-48_7x7mm_P0.5mm | C8304
USBLC6-2SC6 | U2 | Package_TO_SOT_SMD:SOT-23-6 | C7519
DRV8838 | U3,U4 | Package_SON:WSON-8-1EP_2x2mm_P0.5mm_EP0.9x1.6mm | C86667
LMR51430XDDCR | U5 | Package_TO_SOT_SMD:SOT-23-6 | C5185863
16Mhz | Y1 | Crystal:Crystal_SMD_3225-4Pin_3.2x2.5mm | C13738

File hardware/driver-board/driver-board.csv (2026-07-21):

Reference | Qty | Value | Footprint | JLCPCB | JLCPCB Type
BT1 | 1 | BATT (4xAA) | CustomParts:Romi_Chassis_BatteryContactPair_2Slot_14_50mm
BT2 | 1 | BATT (2xAA) | CustomParts:Romi_Chassis_BatteryContactPair_2Slot_14_50mm
C1,C2 | 2 | 10p | Capacitor_SMD:C_0402_1005Metric | C32949 | Basic
C3,C4,C5,C6,C7,C9,C11,C12,C14,C15,C18,C19 | 12 | 100n | Capacitor_SMD:C_0402_1005Metric | C307331 | Basic
C8,C10,C13,C17 | 4 | 10u | Capacitor_SMD:C_0805_2012Metric | C15850 | Basic
C16 | 1 | 220u | Capacitor_SMD:CP_Elec_6.3x7.7 | C190724
C20,C21 | 2 | 22u | Capacitor_SMD:C_1206_3216Metric | C12891 | Basic
C22 | 1 | 10n | Capacitor_SMD:C_0402_1005Metric | C15195 | Basic
C23 | 1 | 1u | Capacitor_SMD:C_0603_1608Metric | C15849 | Basic
D1 | 1 | PWR_ON_LED | LED_SMD:LED_0603_1608Metric | C2286 | Basic
D2 | 1 | STATUS | LED_SMD:LED_0805_2012Metric | C2297 | Basic
F1 | 1 | PTC_2.6A_16V | Fuse:Fuse_1812_4532Metric | C16490
J1 | 1 | Conn_ARM_JTAG_SWD_10 | Connector_PinHeader_1.27mm:PinHeader_2x05_P1.27mm_Vertical_SMD | C2932107
J2 | 1 | USB_C_Receptacle_USB2.0_16P | Connector_USB:USB_C_Receptacle_G-Switch_GT-USB-7010ASV | C2988369
J3 | 1 | CONN_MOTOR_R | Connector_PinSocket_2.54mm:PinSocket_1x06_P2.54mm_Vertical
J4 | 1 | CONN_MOTOR_L | Connector_PinSocket_2.54mm:PinSocket_1x06_P2.54mm_Vertical
L1 | 1 | 5.6u | Inductor_SMD:L_APV_ANR8065 | C96977
Q1 | 1 | AO3401A | Package_TO_SOT_SMD:SOT-23 | C15127 | Basic
Q2 | 1 | AO4407A | CustomParts:AO4407A_SO-8_GSD | C16072
R1,R10,R11,R14,R15 | 5 | 10k | Resistor_SMD:R_0402_1005Metric | C25744 | Basic
R5 | 1 | 1k5 | Resistor_SMD:R_0402_1005Metric | C25867 | Basic
R6,R7 | 2 | 5k1 | Resistor_SMD:R_0402_1005Metric | C25905 | Basic
R12,R13,R16,R18 | 4 | 100k | Resistor_SMD:R_0402_1005Metric | C25741 | Basic
R17 | 1 | 33k | Resistor_SMD:R_0402_1005Metric | C25779 | Basic
R19 | 1 | 22.1k | Resistor_SMD:R_0402_1005Metric | C43473
R20,R21,R23 | 3 | 1k | Resistor_SMD:R_0603_1608Metric | C21190 | Basic
R22 | 1 | 100k | Resistor_SMD:R_0603_1608Metric | C25803 | Basic
SW1 | 1 | SW_Push | Button_Switch_SMD:SW_SPST_TS-1088-xR020 | C720477 | Basic
SW2 | 1 | SK-3296S-01-L2 | CustomParts:SW_SPDT_RightAngle_XKB_SK-3296S-01-L2 | C500051
TP1 | 1 | TP_3V3 | TestPoint:TestPoint_Pad_2.0x2.0mm
TP2 | 1 | TP_GND | TestPoint:TestPoint_Pad_2.0x2.0mm
TP3 | 1 | TP_BAT | TestPoint:TestPoint_Pad_2.0x2.0mm
TP4 | 1 | TP_BAT_SW | TestPoint:TestPoint_Pad_2.0x2.0mm
U1 | 1 | STM32F103CBT6 | Package_QFP:LQFP-48_7x7mm_P0.5mm | C8304
U2 | 1 | USBLC6-2SC6 | Package_TO_SOT_SMD:SOT-23-6 | C7519
U3,U4 | 2 | DRV8838 | Package_SON:WSON-8-1EP_2x2mm_P0.5mm_EP0.9x1.6mm | C86667
U5 | 1 | LMR51430XDDCR | Package_TO_SOT_SMD:SOT-23-6 | C5185863
Y1 | 1 | 16Mhz | Crystal:Crystal_SMD_3225-4Pin_3.2x2.5mm | C13738 | Basic

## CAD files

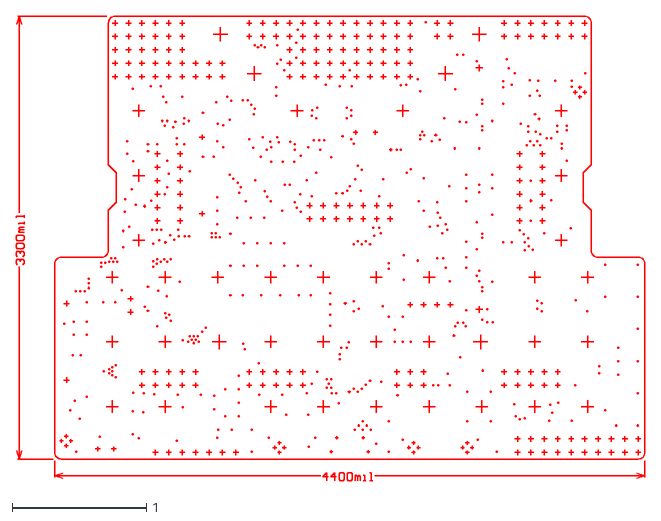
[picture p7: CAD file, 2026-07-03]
docs/rom04a-drill.dxf
4.69 x 3.46

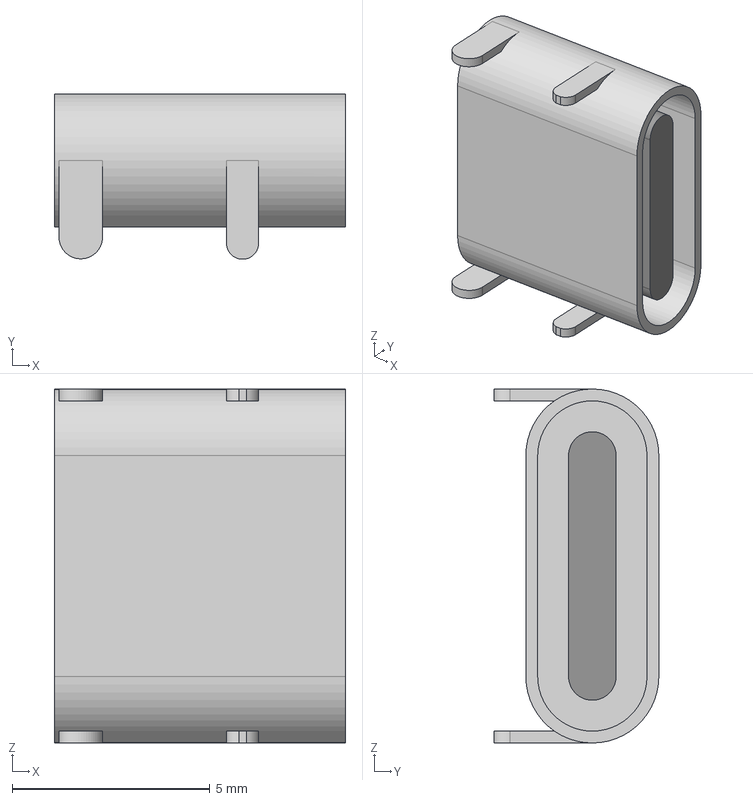
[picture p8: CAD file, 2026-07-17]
hardware/driver-board/3dmodels/GT-USB-7010ASV.step
7.35 x 4.16 x 8.94 mm

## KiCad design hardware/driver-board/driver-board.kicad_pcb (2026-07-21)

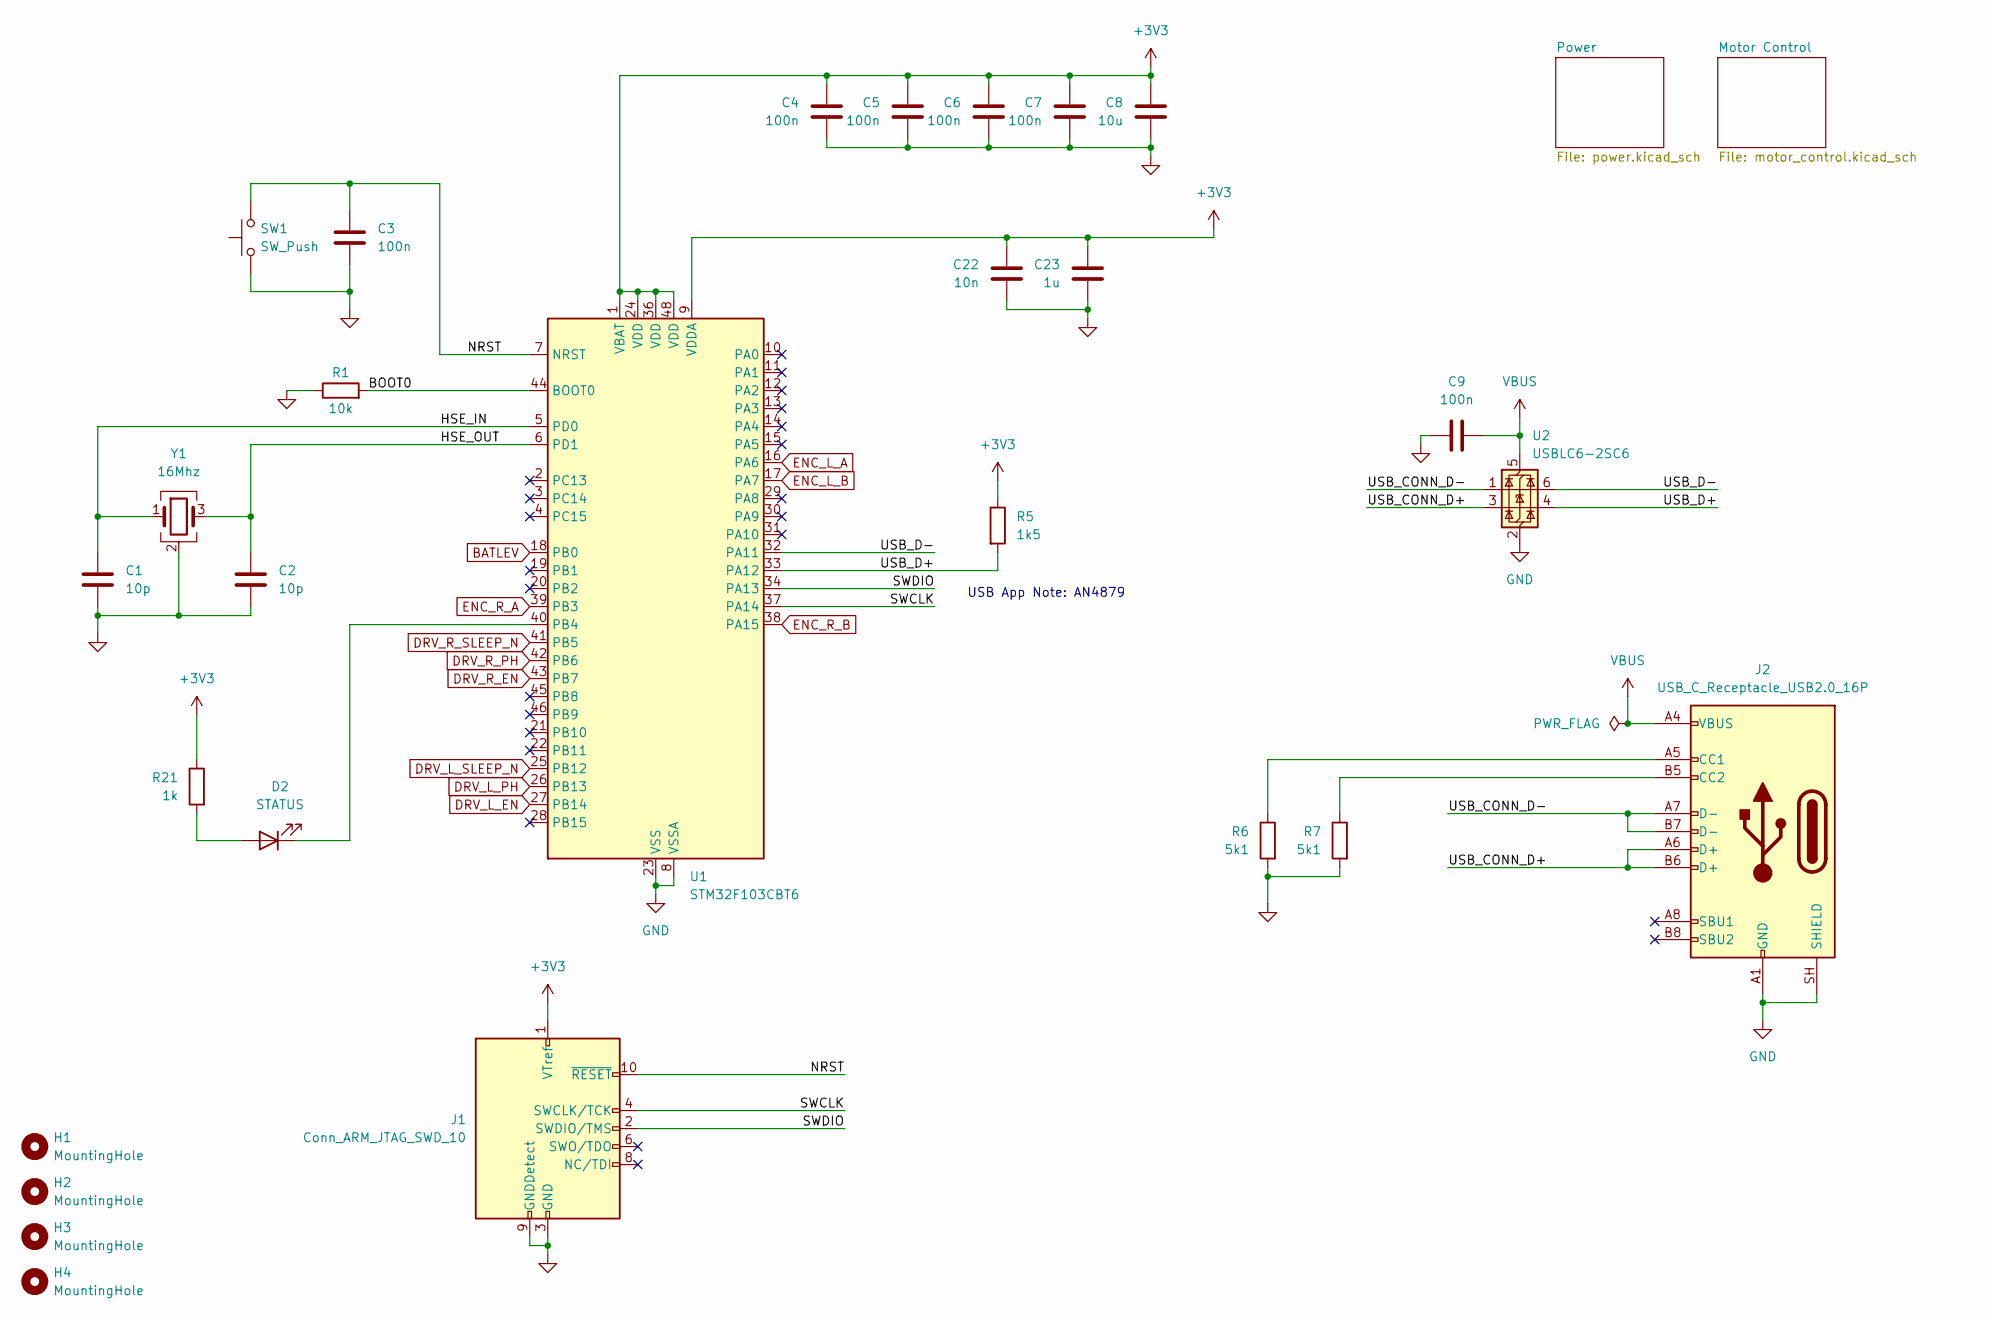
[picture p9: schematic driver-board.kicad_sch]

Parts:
C1, C2: 10p; C_0402_1005Metric; JLCPCB C32949
C3, C4, C5, C6, C7, C9: 100n; C_0402_1005Metric; JLCPCB C307331
C8: 10u; C_0805_2012Metric; JLCPCB C15850
C22: 10n; C_0402_1005Metric; JLCPCB C15195
C23: 1u; C_0603_1608Metric; JLCPCB C15849
D2: STATUS; LED_0805_2012Metric; JLCPCB C2297
H1, H2, H3, H4: MountingHole; MountingHole_2.3mm_2-56
J1: Conn_ARM_JTAG_SWD_10; PinHeader_2x05_P1.27mm_Vertical_SMD; JLCPCB C2932107
J2: USB_C_Receptacle_USB2.0_16P; USB_C_Receptacle_G-Switch_GT-USB-7010ASV; JLCPCB C2988369
R1: 10k; R_0402_1005Metric; MPN 0603WAF1002T5E; JLCPCB C25744
R5: 1k5; R_0402_1005Metric; JLCPCB C25867
R6, R7: 5k1; R_0402_1005Metric; JLCPCB C25905
R21: 1k; R_0603_1608Metric; JLCPCB C21190
SW1: SW_Push; SW_SPST_TS-1088-xR020; JLCPCB C720477
U1: STM32F103CBT6; LQFP-48_7x7mm_P0.5mm; JLCPCB C8304
U2: USBLC6-2SC6; SOT-23-6; JLCPCB C7519
Y1: 16Mhz; Crystal_SMD_3225-4Pin_3.2x2.5mm; JLCPCB C13738

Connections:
+3V3: C4.1, C5.1, C6.1, C7.1, C8.1, C22.1, C23.1, J1.1 (VTref), R5.1, R21.1, U1.1 (VBAT), U1.9 (VDDA), U1.24 (VDD), U1.36 (VDD), U1.48 (VDD); also elsewhere on the board
/BOOT0: R1.2, U1.44 (BOOT0)
/HSE_IN: C1.1, U1.5 (PD0), Y1.1
/HSE_OUT: C2.1, U1.6 (PD1), Y1.3
/NRST: C3.2, J1.10 (~RESET), SW1.2, U1.7 (NRST)
/SWCLK: J1.4 (SWCLK/TCK), U1.37 (PA14)
/SWDIO: J1.2 (SWDIO/TMS), U1.34 (PA13)
/USB_CONN_D+: J2.A6 (D+), J2.B6 (D+), U2.3 (I/O2)
/USB_CONN_D-: J2.A7 (D-), J2.B7 (D-), U2.1 (I/O1)
/USB_D+: R5.2, U1.33 (PA12), U2.4 (I/O2)
/USB_D-: U1.32 (PA11), U2.6 (I/O1)
BATLEV: U1.18 (PB0); also elsewhere on the board
DRV_L_EN: U1.27 (PB14); also elsewhere on the board
DRV_L_PH: U1.26 (PB13); also elsewhere on the board
DRV_L_SLEEP_N: U1.25 (PB12); also elsewhere on the board
DRV_R_EN: U1.43 (PB7); also elsewhere on the board
DRV_R_PH: U1.42 (PB6); also elsewhere on the board
DRV_R_SLEEP_N: U1.41 (PB5); also elsewhere on the board
ENC_L_A: U1.16 (PA6); also elsewhere on the board
ENC_L_B: U1.17 (PA7); also elsewhere on the board
ENC_R_A: U1.39 (PB3); also elsewhere on the board
ENC_R_B: U1.38 (PA15); also elsewhere on the board
GND: C1.2, C2.2, C3.1, C4.2, C5.2, C6.2, C7.2, C8.2, C9.2, C22.2, C23.2, J1.3 (GND), J1.5 (GND), J1.9 (GNDDetect), J2.A1 (GND), J2.A12 (GND), J2.B1 (GND), J2.B12 (GND), J2.SH (SHIELD), R1.1, R6.2, R7.2, SW1.1, U1.8 (VSSA), U1.23 (VSS), U1.35 (VSS), U1.47 (VSS), U2.2 (GND), Y1.2 (G), Y1.4 (G); also elsewhere on the board
unnamed: D2.2 (A), R21.2
unnamed: D2.1 (K), U1.40 (PB4)
unnamed: J2.A5 (CC1), R6.1
unnamed: J2.B5 (CC2), R7.1
VBUS: C9.1, J2.A4 (VBUS), J2.A9 (VBUS), J2.B4 (VBUS), J2.B9 (VBUS), U2.5 (VBUS)

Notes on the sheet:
USB App Note: AN4879

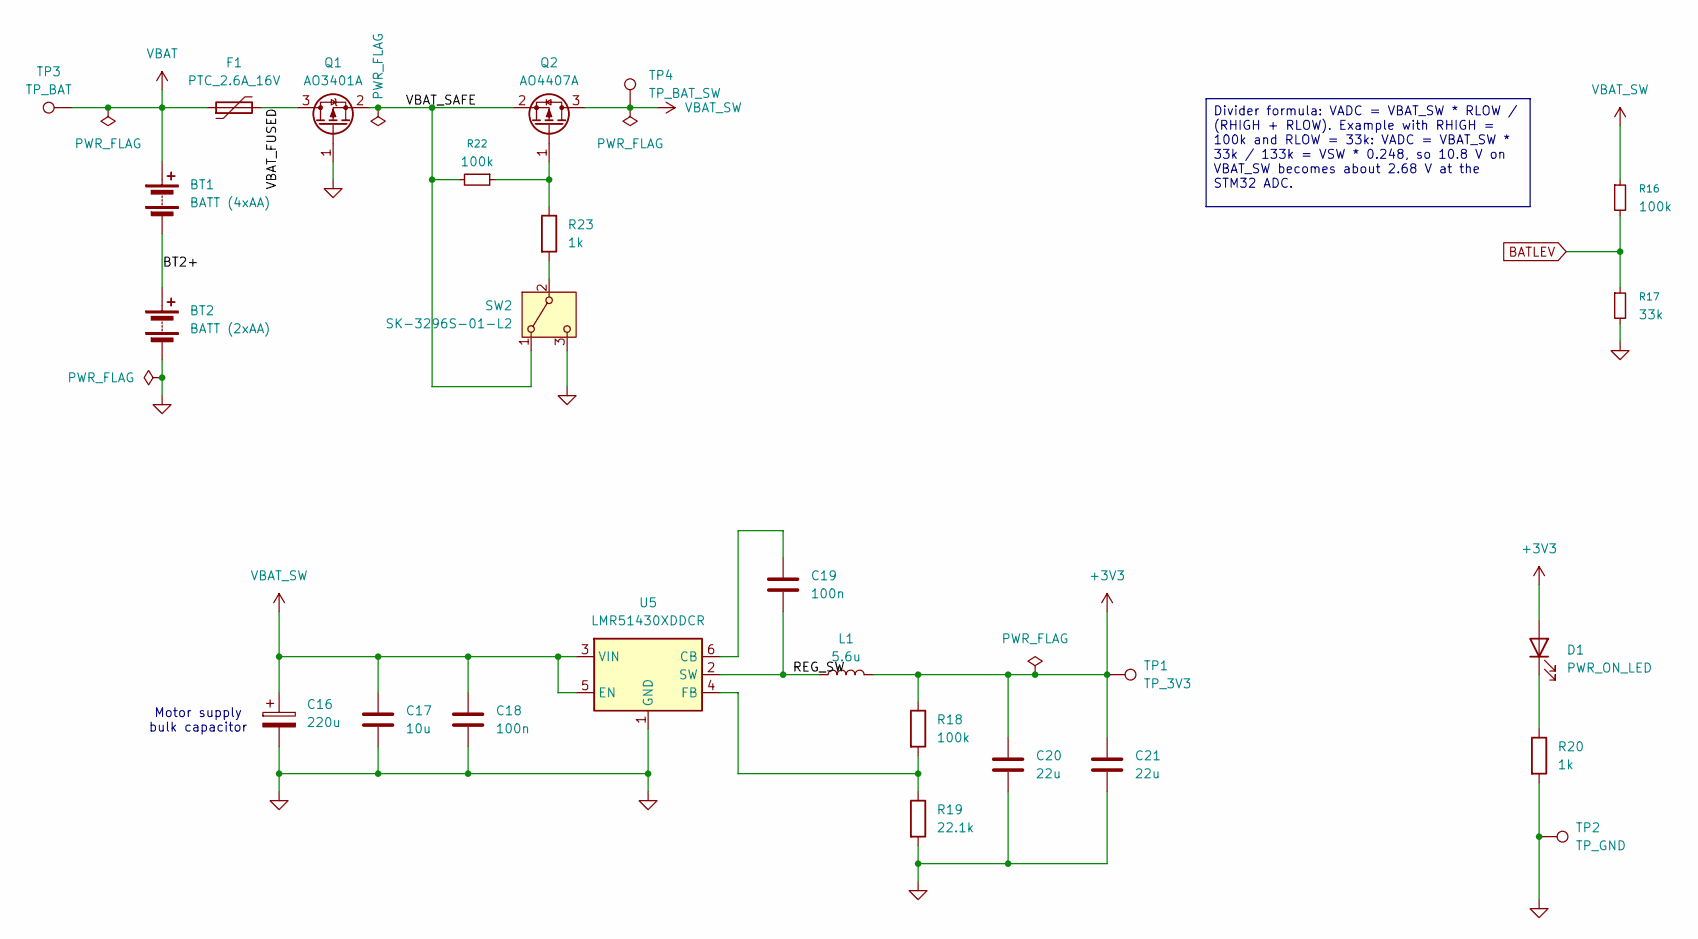
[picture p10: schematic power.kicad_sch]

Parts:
BT1: BATT (4xAA); Romi_Chassis_BatteryContactPair_2Slot_14_50mm
BT2: BATT (2xAA); Romi_Chassis_BatteryContactPair_2Slot_14_50mm
C16: 220u; CP_Elec_6.3x7.7; JLCPCB C190724
C17: 10u; C_0805_2012Metric; JLCPCB C15850
C18, C19: 100n; C_0402_1005Metric; JLCPCB C307331
C20, C21: 22u; C_1206_3216Metric; JLCPCB C12891
D1: PWR_ON_LED; LED_0603_1608Metric; JLCPCB C2286
F1: PTC_2.6A_16V; Fuse_1812_4532Metric; JLCPCB C16490
L1: 5.6u; L_APV_ANR8065; JLCPCB C96977
Q1: AO3401A; SOT-23; JLCPCB C15127
Q2: AO4407A; AO4407A_SO-8_GSD; JLCPCB C16072
R16, R18: 100k; R_0402_1005Metric; JLCPCB C25741
R17: 33k; R_0402_1005Metric; JLCPCB C25779
R19: 22.1k; R_0402_1005Metric; JLCPCB C43473
R20, R23: 1k; R_0603_1608Metric; JLCPCB C21190
R22: 100k; R_0603_1608Metric; JLCPCB C25803
SW2: SK-3296S-01-L2; SW_SPDT_RightAngle_XKB_SK-3296S-01-L2; JLCPCB C500051
TP1: TP_3V3; TestPoint_Pad_2.0x2.0mm
TP2: TP_GND; TestPoint_Pad_2.0x2.0mm
TP3: TP_BAT; TestPoint_Pad_2.0x2.0mm
TP4: TP_BAT_SW; TestPoint_Pad_2.0x2.0mm
U5: LMR51430XDDCR; SOT-23-6; JLCPCB C5185863

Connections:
+3V3: C20.1, C21.1, D1.2 (A), L1.2, R18.1, TP1.1 (1_1); also elsewhere on the board
/Power/BT2+: BT1.2 (-), BT2.1 (+)
/Power/REG_SW: C19.2, L1.1, U5.2 (SW)
/Power/VBAT_FUSED: F1.2, Q1.3 (D)
/Power/VBAT_SAFE: Q1.2 (S), Q2.2 (S), R22.2, SW2.1 (A)
BATLEV: R16.2, R17.1; also elsewhere on the board
GND: BT2.2 (-), C16.2, C17.2, C18.2, C20.2, C21.2, Q1.1 (G), R17.2, R19.2, R20.2, SW2.3 (C), TP2.1 (1_1), U5.1 (GND); also elsewhere on the board
unnamed: D1.1 (K), R20.1
unnamed: Q2.1 (G), R22.1, R23.1
unnamed: R23.2, SW2.2 (B)
unnamed: C19.1, U5.6 (CB)
unnamed: R18.2, R19.1, U5.4 (FB)
VBAT: BT1.1 (+), F1.1, TP3.1 (1_1)
VBAT_SW: C16.1, C17.1, C18.1, Q2.3 (D), R16.1, TP4.1 (1_1), U5.3 (VIN), U5.5 (EN); also elsewhere on the board

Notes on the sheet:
Motor supply bulk capacitor
Divider formula: VADC = VBAT_SW * RLOW / (RHIGH + RLOW). Example with RHIGH = 100k and RLOW = 33k: VADC = VBAT_SW * 33k / 133k = VSW * 0.248, so 10.8 V on VBAT_SW becomes about 2.68 V at the STM32 ADC.

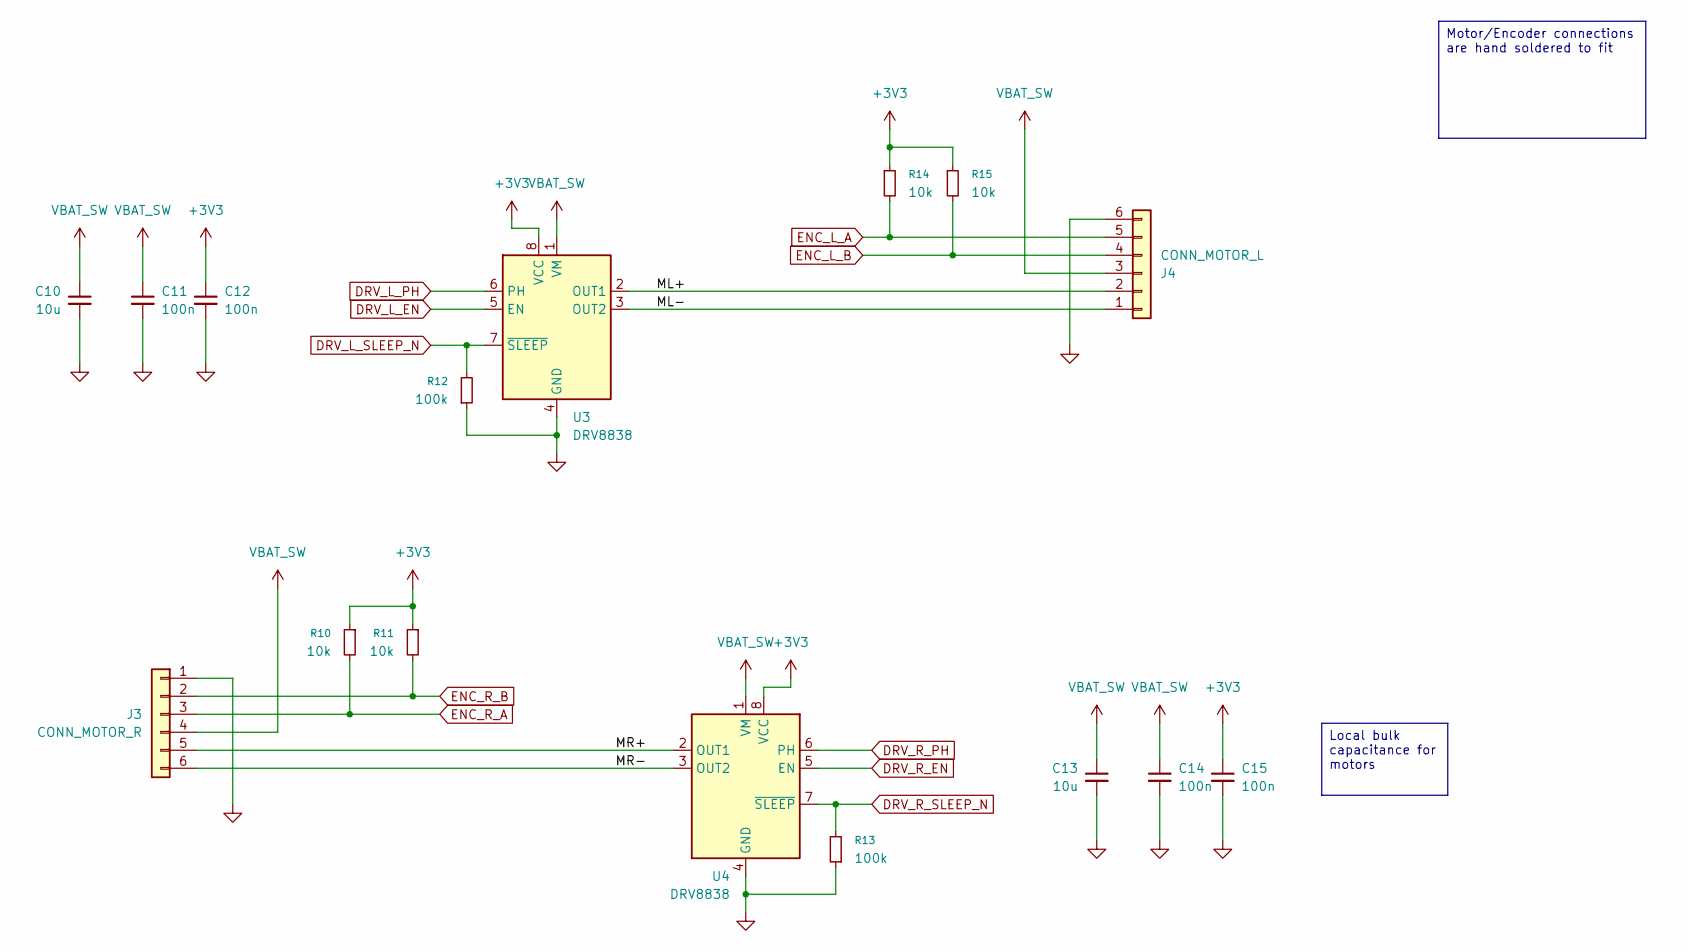
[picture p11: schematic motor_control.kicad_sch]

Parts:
C10, C13: 10u; C_0805_2012Metric; JLCPCB C15850
C11, C12, C14, C15: 100n; C_0402_1005Metric; JLCPCB C307331
J3: CONN_MOTOR_R; PinSocket_1x06_P2.54mm_Vertical
J4: CONN_MOTOR_L; PinSocket_1x06_P2.54mm_Vertical
R10, R11, R14, R15: 10k; R_0402_1005Metric; JLCPCB C25744
R12, R13: 100k; R_0402_1005Metric; JLCPCB C25741
U3, U4: DRV8838; WSON-8-1EP_2x2mm_P0.5mm_EP0.9x1.6mm; JLCPCB C86667

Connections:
+3V3: C12.1, C15.1, R10.1, R11.1, R14.1, R15.1, U3.8 (VCC), U4.8 (VCC); also elsewhere on the board
/Motor Control/ML+: J4.2, U3.2 (OUT1)
/Motor Control/ML-: J4.1, U3.3 (OUT2)
/Motor Control/MR+: J3.5, U4.2 (OUT1)
/Motor Control/MR-: J3.6, U4.3 (OUT2)
DRV_L_EN: U3.5 (EN); also elsewhere on the board
DRV_L_PH: U3.6 (PH); also elsewhere on the board
DRV_L_SLEEP_N: R12.2, U3.7 (~SLEEP); also elsewhere on the board
DRV_R_EN: U4.5 (EN); also elsewhere on the board
DRV_R_PH: U4.6 (PH); also elsewhere on the board
DRV_R_SLEEP_N: R13.2, U4.7 (~SLEEP); also elsewhere on the board
ENC_L_A: J4.5, R14.2; also elsewhere on the board
ENC_L_B: J4.4, R15.2; also elsewhere on the board
ENC_R_A: J3.3, R10.2; also elsewhere on the board
ENC_R_B: J3.2, R11.2; also elsewhere on the board
GND: C10.2, C11.2, C12.2, C13.2, C14.2, C15.2, J3.1, J4.6, R12.1, R13.1, U3.4 (GND), U3.9 (GND), U4.4 (GND), U4.9 (GND); also elsewhere on the board
VBAT_SW: C10.1, C11.1, C13.1, C14.1, J3.4, J4.3, U3.1 (VM), U4.1 (VM); also elsewhere on the board

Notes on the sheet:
Motor/Encoder connections are hand soldered to fit
Local bulk capacitance for motors

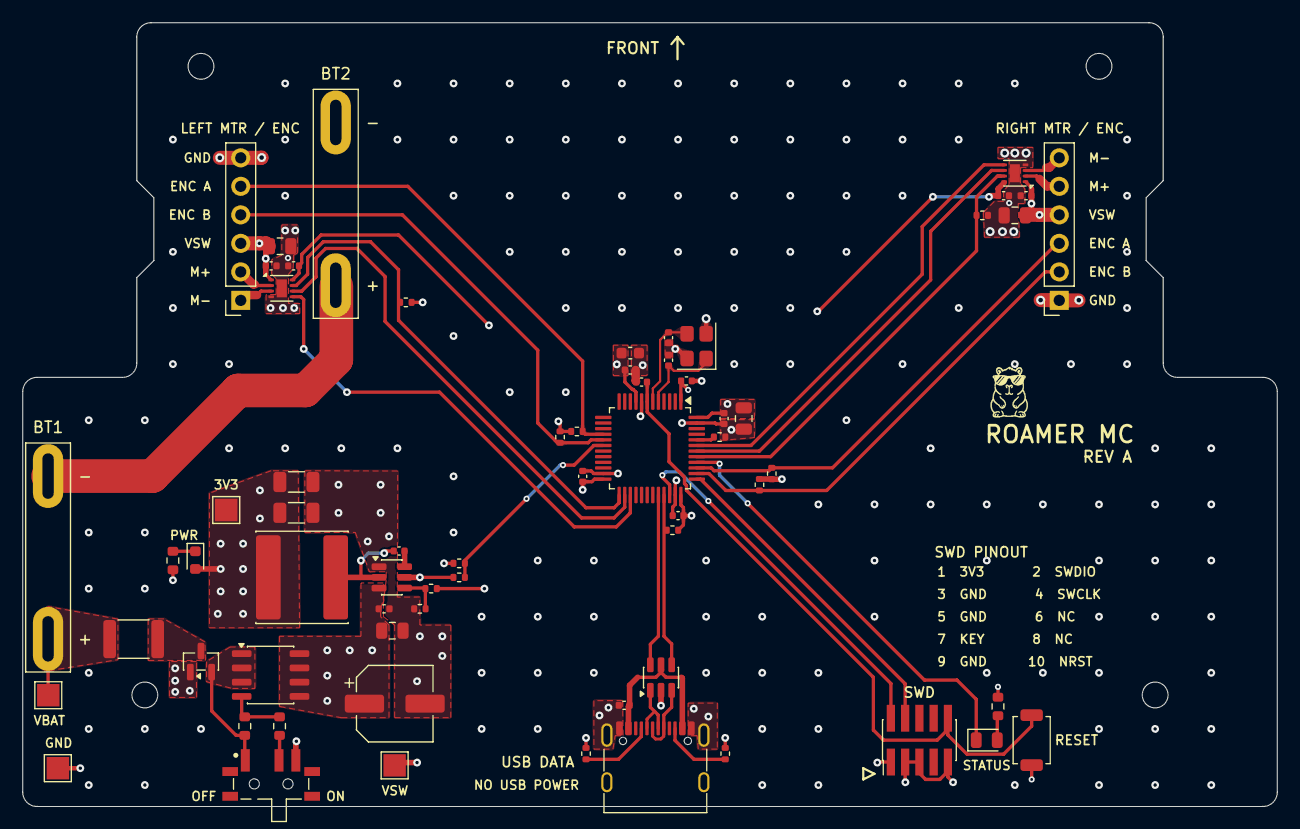
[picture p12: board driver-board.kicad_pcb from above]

Board: 4 copper layers, 111.8 x 69.8 mm, 70 parts (0 on the bottom side), 43 nets.

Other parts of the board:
G1: CAPYBARA_ARTWORK; Capybara_Sunglasses

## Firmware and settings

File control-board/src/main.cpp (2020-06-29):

#include <Kinematics.h>
#include <Odometry.h>
#include <PID.h>
#include <PololuRPiSlave.h>
#include <Romi32U4.h>

#define DEBUG FALSE

// wheel characteristics
#define WHEEL_SEPERATION 0.146     // 146mm = 0.146m
#define WHEEL_CIRCUMFERENCE 0.215  // 6.85cm * pi = 0.215m

// motor characteristics
#define TICKS_PER_REVOLUTION 1440.0
#define MAX_RPM 200  // experimentally found safe upper limit

/* Low Battery Warning
 * The Raspberry Pi seems most supceptable to brown out so I'm focusing on its needs.
 * According to the Romi32U4 onboard regulator docs [https://www.pololu.com/product/2858],
 * a dropout voltage might approach 0.75v during peak loads on the regulator. In order to
 * maintain 5V out, 5.75v must be delivered by the batteries.
 * (I'm not sure if this is correct, but the robot dies pretty much after hitting this point)
 */
#define LOW_BATT_VALUE 6000  // 0.25v buffer

// update rates
#define SAMPLE_DELTA 20       // 50 hz
#define COMMAND_TIMEOUT 1000  // ms
#define IMU_PUB_RATE 50       // 20 hz
#define BATT_CHECK_RATE 8000  // every 8 seconds
#define DEBUG_RATE 500        // 2 hz

struct Data {
    // [input] LEDs
    // 0, 1, 2
    bool led_red, led_green, led_yellow;
    // [output] buttons
    // 3, 4, 5
    bool buttonA, buttonB, buttonC;
    // [output] battery level
    // 6-7
    uint16_t batteryMillivolts;

    // [input] twist command
    // 8
    bool new_twist_command;
    // 9-12
    float twist_linear_x;
    // 13-16
    float twist_angle_z;

    // [output] velocity
    // 17-20
    float vel_linear;
    // 21-24
    float vel_angular;
};

PololuRPiSlave<struct Data, 10> slave;

PololuBuzzer buzzer;
Romi32U4ButtonA buttonA;
Romi32U4ButtonB buttonB;
Romi32U4ButtonC buttonC;
Romi32U4Encoders encoders;
Romi32U4Motors motors;

Kinematics kinematics(WHEEL_CIRCUMFERENCE, WHEEL_SEPERATION);
Odometry leftWheelOdom(TICKS_PER_REVOLUTION);
Odometry rightWheelOdom(TICKS_PER_REVOLUTION);
PID left_pid(-MAX_RPM, MAX_RPM, 0.8, 12.0, 0, SAMPLE_DELTA / 1000.0);
PID right_pid(-MAX_RPM, MAX_RPM, 0.8, 12.0, 0, SAMPLE_DELTA / 1000.0);

void setup() {
#ifdef DEBUG
    Serial.begin(57600);
    Serial.println("Roamer control board online");
#endif

    // I2C address 20
    slave.init(20);

    // startup sound
    // TODO: make unique
    buzzer.play("v10>>e16>>>g16");

    // allows for TEMPORARY extra power to motors
    // must ensure not constantly overdriving motor
    motors.allowTurbo(true);

    ledYellow(false);
    ledGreen(true);
    ledRed(false);
}

#ifdef DEBUG
void printDebugInfo() {
    Serial.print("BUTTONS: ");
    Serial.print(slave.buffer.buttonA);
    Serial.print(" ");
    Serial.print(slave.buffer.buttonB);
    Serial.print(" ");
    Serial.print(slave.buffer.buttonC);
    Serial.println();

    Serial.print("BATT: ");
    Serial.print(slave.buffer.batteryMillivolts, DEC);
    Serial.println("ma");

    Serial.print("Encoders: ");
    Serial.print(encoders.getCountsLeft(), DEC);
    Serial.print(" ");
    Serial.print(encoders.getCountsRight(), DEC);
    Serial.println();

    Serial.println();
}
#endif

void move() {
    // calculate required wheel RPMs for requested motion
    Kinematics::rpm req_rpm =
        kinematics.rpmForMotion(slave.buffer.twist_linear_x, slave.buffer.twist_angle_z);

    // get current RPM of each motor
    unsigned long ms = millis();
    float left_rpm = leftWheelOdom.getRPM(encoders.getCountsLeft(), ms);
    float right_rpm = rightWheelOdom.getRPM(encoders.getCountsRight(), ms);

    // calculate PID RPM values for motors based on measured vs required
    motors.setLeftSpeed(left_pid.calculate(req_rpm.left_motor, left_rpm));
    motors.setRightSpeed(right_pid.calculate(req_rpm.right_motor, right_rpm));

    // send velocity back to i2c master
    Kinematics::velocities vel = kinematics.getVelocities(left_rpm, right_rpm);
    slave.buffer.vel_linear = vel.linear;
    slave.buffer.vel_angular = vel.angular;
}

void stop() {
    // perform full stop by zeroing out command values
    // next move() command call will stop motors
    slave.buffer.twist_linear_x = 0;
    slave.buffer.twist_angle_z = 0;
}

void loop() {
    // get the latest data from master
    slave.updateBuffer();

    // READ: Button states
    slave.buffer.buttonA = buttonA.isPressed();
    slave.buffer.buttonB = buttonB.isPressed();
    slave.buffer.buttonC = buttonC.isPressed();

    // WRITE: LED values
    ledRed(slave.buffer.led_red);
    ledGreen(slave.buffer.led_green);
    ledYellow(slave.buffer.led_yellow);

    // STOP the robot if no new command received within timeout
    unsigned long ms = millis();
    static unsigned long prevCommandTime = 0;
    if (slave.buffer.new_twist_command == true) {
        // reset command timeout & mark as seen
        prevCommandTime = ms;
        slave.buffer.new_twist_command = false;
    } else if (ms - prevCommandTime >= COMMAND_TIMEOUT) {
        stop();
    }

    // DRIVE the robot
    static unsigned long lastCommandUpdate = 0;
    if (ms - lastCommandUpdate >= SAMPLE_DELTA) {
        move();
        lastCommandUpdate = ms;
    }

    // publish IMU data
    static unsigned long lastIMUPublish = 0;
    if (ms - lastIMUPublish >= IMU_PUB_RATE) {
        // TODO: publish IMU data now (is ODOM needed too?)
        lastIMUPublish = ms;
    }

    // battery low warning chime
    static unsigned long lastBatteryCheckTime = 0;
    if (ms - lastBatteryCheckTime >= BATT_CHECK_RATE) {
        // READ: Battery voltage
        slave.buffer.batteryMillivolts = readBatteryMillivolts();

        if (readBatteryMillivolts() < LOW_BATT_VALUE && !usbPowerPresent()) {
            buzzer.play("v12>>f#>>>g");
        }
        lastBatteryCheckTime = ms;
    }

    // make data available to master
    slave.finalizeWrites();

#ifdef DEBUG
    static unsigned long lastDebugTime = 0;
    if (ms - lastDebugTime >= DEBUG_RATE) {
        printDebugInfo();
        lastDebugTime = ms;
    }
#endif
}

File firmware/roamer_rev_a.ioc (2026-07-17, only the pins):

Mcu.UserName=STM32F103CBTx
PA11.Signal=USB_DM
PA12.Signal=USB_DP
PA13.Signal=SYS_JTMS-SWDIO
PA14.Signal=SYS_JTCK-SWCLK
PA15.GPIO_Label=ENC_R_B
PA15.Signal=S_TIM2_CH1_ETR
PA6.GPIO_Label=ENC_L_A
PA6.Signal=S_TIM3_CH1
PA7.GPIO_Label=ENC_L_B
PA7.Signal=S_TIM3_CH2
PB0.GPIO_Label=BATLEV
PB0.Signal=ADCx_IN8
PB10.GPIO_Label=SENSOR_I2C_SCL
PB10.Signal=I2C2_SCL
PB11.GPIO_Label=SENSOR_I2C_SDA
PB11.Signal=I2C2_SDA
PB12.GPIO_Label=DRV_L_SLEEP_N
PB12.Signal=GPIO_Output
PB13.GPIO_Label=DRV_L_PH
PB13.Signal=GPIO_Output
PB14.GPIO_Label=DRV_L_EN
PB14.Signal=S_TIM1_CH2N
PB5.GPIO_Label=DRV_R_SLEEP_N
PB5.Signal=GPIO_Output
PB3.GPIO_Label=ENC_R_A
PB3.Signal=S_TIM2_CH2
PB6.GPIO_Label=DRV_R_PH
PB6.Signal=GPIO_Output
PB7.GPIO_Label=DRV_R_EN
PB7.Signal=S_TIM4_CH2
PC13-TAMPER-RTC.GPIO_Label=LED_HEARTBEAT
PC13-TAMPER-RTC.Signal=GPIO_Output
PD0-OSC_IN.Signal=RCC_OSC_IN
PD1-OSC_OUT.Signal=RCC_OSC_OUT

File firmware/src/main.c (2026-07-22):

#include "board.h"
#include "usb_cdc.h"

static const uint8_t usb_heartbeat[] = "roamer heartbeat\r\n";

int main(void) {
    const bool external_clock_ready  = board_init();
    const uint32_t blink_interval_ms = external_clock_ready ? 500U : 100U;
    uint32_t last_toggle_ms          = board_millis();
    uint32_t last_usb_heartbeat_ms   = board_millis();
    bool led_on                      = false;

    if (external_clock_ready) {
        usb_cdc_init();
    }

    for (;;) {
        const uint32_t now_ms = board_millis();

        if ((uint32_t) (now_ms - last_toggle_ms) >= blink_interval_ms) {
            last_toggle_ms += blink_interval_ms;
            led_on = !led_on;
            board_led_set(led_on);
        }

        if (external_clock_ready &&
            (uint32_t) (now_ms - last_usb_heartbeat_ms) >= 1000U) {
            last_usb_heartbeat_ms = now_ms;
            if (usb_cdc_connected()) {
                (void) usb_cdc_try_write(usb_heartbeat,
                                          (uint16_t) (sizeof(usb_heartbeat) - 1U));
            }
        }

        __asm volatile("wfi");
    }
}

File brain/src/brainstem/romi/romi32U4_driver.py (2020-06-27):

#!/usr/bin/python2
#
# Notes:
# read_unpack, write_pack types quick reference
# https://docs.python.org/3.6/library/struct.html#format-characters
# ? - bool           - 1
# B - unsigned char  - 1
# h - short          - 2
# H - unsigned short - 2
# f - float          - 4
#
# Copyright Pololu Corporation.  For more information, see https://www.pololu.com/

import smbus
import struct
import time

class Romi32U4Driver:
    def __init__(self):
        # open I2C port
        self.bus = smbus.SMBus(1)

    def close(self):
        self.bus.close()

    def read_raw(self, size):
        try:
            byte_list = [self.bus.read_byte(20) for _ in range(size)]
        except IOError:
            print("IOError Detected: read_raw")
            return None
        return byte_list


    def read_unpack(self, address, size, format):
        # Ideally we could do this:
        #    byte_list = self.bus.read_i2c_block_data(20, address, size)
        # But the AVR's TWI module can't handle a quick write->read transition,
        # since the STOP interrupt will occasionally happen after the START
        # condition, and the TWI module is disabled until the interrupt can
        # be processed.
        #
        # A delay of 0.0001 (100 us) after each write is enough to account
        # for the worst-case situation in our example code.
        self.bus.write_byte(20, address)
        time.sleep(0.0002)
        byte_list = [self.bus.read_byte(20) for _ in range(size)]
        return struct.unpack(format, bytes(bytearray(byte_list)))

    def write_pack(self, address, format, *data):
        for i in range(2):
            try:
                data_array = list(struct.pack(format, *data))
                self.bus.write_i2c_block_data(20, address, data_array)
            except IOError:
                write_fail_flag = True
                print("IOError Detected: write_pack")
                continue
            break
        time.sleep(0.0001) 

    """
    OUTPUT commands
    """

    def leds(self, red, green, yellow):
        self.write_pack(0, '???', red, green, yellow)

    def _new_twist(self):
        """
        Mark current Twist as a fresh value
        Resets command timeout on robot
        """
        self.write_pack(8, '?', True)

    def twist(self, linear_x_m_s, angular_z_rad_s):
        """
        Sets a new Twist command for the robot to follow
        """
        self.write_pack(9, 'ff', linear_x_m_s, angular_z_rad_s)
        self._new_twist()

    """
    INPUT robot state
    """

    def read_buttons(self):
        return self.read_unpack(3, 3, "???")

    def read_battery_millivolts(self):
        return self.read_unpack(6, 2, "H")[0]

    def read_linear_velocity(self): 
        """
        Linear and velocity of robot
        Hopefully as a result of the current twist command
        """
        return self.read_unpack(17, 4, 'f')
    
    def read_angular_velocity(self): 
        """
        Angular and velocity of robot
        """
        return self.read_unpack(21, 4, 'f')

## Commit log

2020-06-20 Started Romi 32u4 control board firmware
2020-06-21 Some basic information being sent over i2c comms
2020-06-23 Setup some test cases around odometry and kinematics
2020-06-24 Passing some odometry and kinematics tests
2020-06-26 Setup skeleton and test for PID control
2020-06-26 Not even a full PID controller and the robot is hitting its tests
2020-06-26 PID meeting some test targets
    [data.csv]
2020-06-27 Pulled settings over to main project from tests, still not good PID values
2020-06-27 Driver can change LED values on control board
2020-06-27 Add low battery warning chime to give time to shutdown RPI before brown out
    [main.cpp]
2020-06-27 Basic driver to brainstem setup
2020-06-27 Adding reporting of velocity back to brain
2020-06-28 Compute actual velocity given reading of wheel RPM
2020-06-28 Wasn't reporting battery MV because it was added to i2c packet AFTER send
2020-06-28 Publishing what I have so far of odometry data
2020-06-29 Added lino pid submodule
2026-07-03 Document custom Romi control board plan
    [rom04a-drill.dxf]
2026-07-05 Reorganize legacy Romi implementation
    [data.csv]
2026-07-08 Add Rev A hardware design baseline
    [driver-board.kicad_pcb, driver-board.kicad_sch, motor_control.kicad_sch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]
2026-07-08 Add buck regulator parts
    [power.kicad_sch]
2026-07-09 Checkpoint driver board schematic
    [driver-board.kicad_sch, motor_control.kicad_sch, power.kicad_sch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]
2026-07-10 Wrap up Rev A schematic pre-layout tasks
    [driver-board.kicad_sch, motor_control.kicad_sch, power.kicad_sch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]
2026-07-10 Add Romi chassis reference PDF
2026-07-10 Add custom power entry footprints
    [driver-board.kicad_sch, power.kicad_sch]
2026-07-10 Add driver board BOM export
    [driver-board.csv]
2026-07-10 Update driver board power schematic
    [power.kicad_sch]
2026-07-12 Add ROMI-compatible driver board geometry
    [driver-board.kicad_pcb]
2026-07-12 Complete Romi-compatible board placement and power switching
    [driver-board.csv, driver-board.kicad_pcb, driver-board.kicad_sch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]
2026-07-13 Review and harden Rev A driver board
    [driver-board.csv, driver-board.kicad_pcb, driver-board.kicad_sch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]
2026-07-14 Refine driver board placement and capacitor footprints
    [driver-board.kicad_pcb, driver-board.kicad_sch, motor_control.kicad_sch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]
2026-07-14 Refine driver board placement and motor power checks
    [driver-board.kicad_pcb, driver-board.kicad_sch, motor_control.kicad_sch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]
2026-07-14 Refine switch footprint and board placement
    [driver-board.kicad_pcb]
2026-07-15 Refine Rev A PCB placement and decoupling
    [driver-board.kicad_pcb, driver-board.kicad_sch, motor_control.kicad_sch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]
2026-07-16 Route MCU oscillator and improve grounding
    [driver-board.kicad_pcb]
2026-07-16 Add VDDA supply filter
    [driver-board.kicad_pcb, driver-board.kicad_sch]
2026-07-17 Update driver board USB-C and power circuitry
    [driver-board.kicad_pcb, driver-board.kicad_sch]
2026-07-17 Refine driver board layout and 3D models
    [GT-USB-7010ASV.step, driver-board.kicad_pcb, driver-board.kicad_sch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]
2026-07-17 Checkpoint left motor driver layout
    Capture the routed left motor-driver state before relocation, align the STM32 IOC labels with the schematic pin mapping, and save the current Rev A purchasing and Rev B planning notes.
    [driver-board.kicad_pcb, driver-board.kicad_sch]
2026-07-17 Checkpoint left driver and firmware pin mapping
    [driver-board.kicad_pcb, driver-board.kicad_sch, motor_control.kicad_sch]
2026-07-17 Complete motor driver layouts and pin mapping
    [driver-board.kicad_pcb, driver-board.kicad_sch, motor_control.kicad_sch]
2026-07-17 Checkpoint status LED move to PB4
    [driver-board.kicad_pcb, driver-board.kicad_sch]
2026-07-17 Finalize Rev A PCB and hardware docs
    [driver-board.csv, driver-board.kicad_pcb, driver-board.kicad_sch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]
2026-07-21 Archive Rev A JLCPCB manufacturing submission
    [driver-board-jlc-bom.csv, driver-board.csv, driver-board.kicad_pcb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]
